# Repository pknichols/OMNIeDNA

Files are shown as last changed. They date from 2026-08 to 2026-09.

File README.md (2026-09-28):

# OMNIeDNA (*O*pen, *M*odular, *N*on-invasive, *I*n-situ eDNA) Sampler
## The versatile 3D-printed eDNA sampler to maximize detection and minimize complexity

---

> [!IMPORTANT]
> **Preliminary tool, subject to on-going development.**

<p align="center">
  OMNIeDNA
</p>

The OMNIeDNA sampler is a modular environmental DNA (eDNA) concentration system built around a standard 50 mm cotton swab pad secured within a threaded connection ring. By placing this simple, low-cost membrane at the point of water entry, the OMNIeDNA filter system creates a consistent, focused filtration interface that works across virtually any water sampling scenario. Yes, you can also use more traditional filter membranes (48-52 mm diameter) if you feel so inclined!

Whether deployed passively or with minimal active force, the system directs water through the cotton membrane, capturing cellular material and extracellular DNA efficiently on a substrate that is both widely available and easily processed for downstream DNA extraction. The threaded ring architecture allows users to adapt the same filtration core to a wide range of sampling containers, flow conditions, or collection methods, making affordable ecosystem-wide surveying accessible in diverse environments. The OMNIeDNA filter system is an inexpensive tool that puts the power of eDNA sampling into the hands of non-specialist users. Simple materials, limitless adaptability.

<p align="center">
  torrent
</p>

- [**OMNIeDNA TORRENT**](./OMNIeDNA_TORRENT_kit.stl) – A torpedo-shaped sampler designed specifically for use in streams and rivers, or to be deployed from behind recreational vessels and/or watercraft. So versatile that it can be deployed using buoys, docks, bridges, kayaks, dinghies, SUPs... heck, we'd even tie it to a unicorn floaty! Use the [**OMNIeDNA TORRENT MINI**](./OMNIeDNA_TORRENT_MINI_kit.stl) on a fishing pole for casting or trolling for eDNA!

&nbsp;

---

<p align="center">
  omnifilter_rapid
</p>

- [**OMNIeDNA RAPID**](./OMNIeDNA_RAPID_kit.stl) – Universal 1.0/1.5-liter plastic bottle threaded attachment (PET bottles with the standard 30 mm caps) for rapid filtering of collected water samples. Make sure you enjoy that soda first though, and give it a good cleaning before use!

&nbsp;

---

<p align="center">
  omnifilter
</p>

- [**OMNIeDNA BULK**](./OMNIeDNA_BULK_kit.stl) – Universal 5.0/5.1-liter plastic bottle threaded attachment (PET carboys with a 50 mm cap) for large-volume filtration of collected water samples. You know, the kind of water jugs you keep in the hidden bunker for the zombie apocalypse?

&nbsp;

---

<p align="center">
  canopy
</p>

- [**OMNIeDNA CANOPY**](./OMNIeDNA_CANOPY_kit.stl) – A rain/sleet/snow collection adapter to maximize filtration of canopy throughfall. When used in the rain with a plastic tarp (sorry, cannot 3D print that piece), the attached plastic bottle lets you know how much water you have collected. When used in sleet/snow, bring the bottle to room temperature to melt and invert to filter the collected water. We didn't want to exclude our (Ant)arctic partners!!

&nbsp;

---

<p align="center">
  omnicartridge
</p>

- [**OMNIeDNA Cartridges**](./Optional/mixed_bed2x2.stl) – Reusable filter membrane holders (for use with filter membranes of diameter < 52 mm) enable adjustable pre-filtration based on debris load and environment type, allow sterile batch assembly for fast field deployment, and are easy to decontaminate after use.

&nbsp;

---

<p align="center">
  multi_rack
</p>

- [**OMNIeDNA Multi Rack**](./Optional/multi_rack.stl) – Facilitates the transfer of filter membranes into sample storage tubes in the laboratory or field. Steadily holds 15 mL and 5 mL conical tubes, plus two OMNIeDNA Cartridges. Drainage holes for easy bleach-decontamination and drying.

&nbsp;

&nbsp;

---

## Instructions

The OMNIeDNA system may look complex with a lot of pieces, but whether you're dangling it off a boat or screwing it onto a soda bottle on shore, you only ever need **one of each** to get rolling.

We call it **The ABCs**. Pick your **A**, pick your **B**, pick your **C**, and you are ready to sample.

**That's it.** Three pieces. So many configurations. Go get that eDNA. 🧬

&nbsp;

### (A) – The Adapter

This is the top half. It's where the water enters the system. Your choice depends on where you plan to sample:

| Adapter | Other Required Gear | Best Suited For | Filament Used | Approx. Print Time | Print Settings |
|---|---|---|-----|---|---|
| [**TORRENT Cone**](./A_components/torrent_cone.stl) | TORRENT Tail, rope | Moving aquatic environments (rivers, streams, towed behind a kayak or small boat) | 40g | 1hr 15min | Brim only |
| [**RAPID Adapter**](./A_components/rapid_adapter.stl) | 1.0/1.5L plastic bottles, Wide/Narrow Base | Great for quick, grab-and-go field sampling. Uses plastic bottles that are universally available. | 50g | 2hr 5min | Brim only |
| [**BULK Adapter**](./A_components/bulk_adapter.stl) | 5.1L plastic carboy, Wide Base | Perfect for sampling water from larger jugs, meaning more eDNA. However, larger jugs may be more difficult to source. | 55g | 2hr 15min | Brim only |

&nbsp;

---

### (B) – The Base

This is the bottom half. It dictates how the sampler stabilizes while water flows out.

| Base | Other Required Gear | Best Suited For | Filament Used | Approx. Print Time | Print Settings |
|---|---|---|-----|---|---|
| [**TORRENT Tail**](./B_components/torrent_tail.stl) | TORRENT Cone, rope | Moving aquatic environments (rivers, streams, towed behind a kayak or small boat) | 240g | 10hr | Outer Brim, 50% infill |
| **Wide Base** | BULK or RAPID Adapter, 5.1L or 1.0/1.5L plastic bottle | Dry land / bench-top filtration, with a sturdy footprint that is less likely to tip over while you work | | | Outer Brim |
| [**Narrow Base**](./B_components/narrow_base.stl) | BULK or RAPID Adapter, 5.1L or 1.0/1.5L plastic bottle | Compact fieldwork (coolers, backpacks, tight spaces) or uneven ground where it can instead be hung for maximum portability | 35g | 1hr 30min | Outer Brim |
| [**CANOPY Bulkhead**](./B_components/canopy_bulkhead.stl) | BULK or RAPID Adapter, 5.1L or 1.0/1.5L plastic bottle, durable plastic sheet (waterproof tarp, shower curtain liner, etc.), rope | Used as a through-fitting for a large plastic sheet or tarp to collect rainwater while suspended from the trees | 25g | 1hr 30min | Tight supports |

&nbsp;

---

### (C) – The Connector

This is the middle piece... a threaded ring that literally **connects your chosen (A) to your chosen (B)**.

| Connector | Required For | Filament Used | Approx. Print Time | Print Settings |
|---|---|-----|---|---|
| [**Connector Ring**](./C_components/connector_ring.stl) | All builds | 20g | 40min | Outer Brim |

&nbsp;

---

### Optional Extras

For fragile filter membranes (or those < 50 mm in diameter), the OMNIeDNA Cartridges are highly recommended to provide stability and reduce likelihood of filter membrane loss.

- Pre-load your sterile filter membranes *before* you leave. No more fumbling with delicate filter membranes in the field!
- At the field site, just pop the cartridge in, sample, pop it out, and seal it in a plastic bag.
- Putting your filter membranes into sample tubes? Use the tube rack as a stable platform to transfer membranes from cartridges to 15 or 5 mL conical sample tubes.

| Extra | Description | Filament Used | Approx. Print Time | Print Settings |
|---|---|-----|---|---|
| [**Support Cartridge**](./Optional/support_cartridge.stl) | 6 mm openings to provide support for fragile filter membranes while maximizing the contact area of filtered water | 5g | 20min | 100% infill |
| [**Mesh Cartridge**](./Optional/mesh_cartridge.stl) | Fine 2.5 mm mesh for excluding large debris like leaves, sticks, and other material that may be in the water. It also provides support for fragile filter membranes, reducing the chances of them ripping during deployments | 5g | 15min | 100% infill |
| [**Multi Rack**](./Optional/multi_rack.stl) | Tube rack for holding samples while in the laboratory or in the field, greatly reducing the chances of knocking something over. Even holds two membrane cartridges for easy transfer directly into sample storage tubes. | 110g | 3hr 45min | Outer Brim |

&nbsp;

&nbsp;

---

### Putting It All Together

Here are some theoretical builds/use cases (no, we haven't tested them all... yet):

| Use Case | System | Printed Parts | Justification |
|---|----|---|---|
| *What fish are in my local river? (Mostly curious)* | TORRENT | [**TORRENT Cone (A)**](./A_components/torrent_cone.stl), [**TORRENT Tail (B)**](./B_components/torrent_tail.stl), [**Connector Ring (C)**](./C_components/connector_ring.stl), [**Mesh Cartridge (Optional)**](./Optional/mesh_cartridge.stl) | Moving water requires the torpedo-shaped [**OMNIeDNA TORRENT**](./OMNIeDNA_TORRENT_kit.stl) to guide water through the opening. Use a mesh cartridge to keep out larger debris and focus eDNA more efficiently, while minimizing tearing of the filter membrane. |
| *What fish are in my local river? (I'm a fisherman)* | TORRENT MINI |  | Attach the torpedo-shaped [**OMNIeDNA TORRENT MINI**](./OMNIeDNA_TORRENT_MINI_kit.stl) to a fishing pole and cast out multiple times, focusing eDNA efficiently onto smaller 25 mm membranes. Simple and fun! |
| *What birds visit my birdbath?* | RAPID |[**RAPID Adapter (A)**](./A_components/rapid_adapter.stl), [**Narrow Base (B)**](./B_components/narrow_base.stl), [**Connector Ring (C)**](./C_components/connector_ring.stl) | Use a standard plastic bottle to collect birdbath water (multiple times, the more the better, but leave some for the birds!) with the [**OMNIeDNA RAPID**](./OMNIeDNA_RAPID_kit.stl). |
| *Are there aquatic invasive species here?* | BULK | [**BULK Adapter (A)**](./A_components/bulk_adapter.stl), **Wide Base (B)**, [**Connector Ring (C)**](./C_components/connector_ring.stl), [**Support Cartridge (Optional)**](./Optional/support_cartridge.stl) | Maximize detection of rare species and the volume of water that passes through the filter membrane by using a larger 5L bottle (multiple times, the more the better!) and the [**OMNIeDNA BULK**](./OMNIeDNA_BULK_kit.stl). Use the support cartridge to maximize surface area while minimizing the chances of ripping the filter membrane. |
| *What are the birds, the bees, and the trees?* | CANOPY | [**RAPID Adapter (A)**](./A_components/rapid_adapter.stl), [**CANOPY Bulkhead (B)**](./B_components/canopy_bulkhead.stl), [**Mesh Cartridge (Optional)**](./Optional/mesh_cartridge.stl) | Harvest rain throughfall under forested canopies using the [**OMNIeDNA CANOPY**](./OMNIeDNA_CANOPY_kit.stl) to easily sample plant and animal communities. Use the mesh cartridge to exclude leaves, sticks, and other debris that may be caught as well. Know how much rain you filtered by collecting it in a standard plastic bottle. |

&nbsp;

&nbsp;

---

## Helpful Tips

- **OMNIeDNA TORRENT:** The sampler stays underwater via hydrodynamic design, but it relies on water flow to maintain negative buoyancy. Securely attach a ballast weight (dive weight, brick, anchor, or large rock) to any of the gear attachment points. When you MUST add a ballast weight:

  - *Too slow:* Water speed < 1 knot (~0.5 m/s) — not enough flow to push it down.

  - *Too fast:* Water speed > 7 knots (~3.5 m/s) — risk of planing or lifting out of the water.

  - *Too deep:* Sampling near the bottom of the water column. 

- **OMNIeDNA BULK/RAPID:** When using a plastic bottle, filtration will be much easier if you can poke a hole in the bottom! That way, when you invert the system, it will drain smoothly through the filter. Use tape to temporarily seal the hole while sampling (or simpler still, just be really quick)!

- **OMNIeDNA CANOPY:** While the system can theoretically use any waterproof sheet material, those that can hold up to stormy weather, rough terrain, and routine decontamination with bleach will inevitably perform best (e.g., thick PVC). 

  - *Hanging:* Pick a location that has plenty of trees and bring plenty of extra string to secure the corners as high as you can reach.
  - *Tensioning:* Use a tensioning knot such as a prusik, taut-line hitch, or siberian hitch attached to each corner to easily adjust where water collects. Bring a bottle of water to test where it gathers.
  - *Collecting:* Poke a hole in the top of your collection bottle to allow air to easily vent and water to enter. This also allows extra water can escape during large storms, instead of pooling up on the tarp. Size your collection bottle to the expected amount of rain (i.e., RAPID adapter for quick sampling, BULK adapter for lots of rain/large surface area tarps)

&nbsp;

## Printer Specifications

All components have been successfully printed on a Prusa MK4S using the following parameters:

- **Filament:** 1.75mm PETG or ABS plastic (recommended over PLA for toughness, frequent use in harsh environments). ABS components can be smoothed with an Acetone vapor bath to facilitate routine bleach decontamination.
- **Infill:** Gyroid, 30%+ (superior strength-to-weight ratio using less material, reducing print costs)
- **Layer height:** 0.20 mm
- **Minimum perimeters per layer:** 4
- **Print temperature:** 220°C – 260°C (PETG/ABS); 
- **Heated bed:** 70 – 80°C (PETG); 90 – 110°C (ABS; enclosure and ventilation recommended)
- **Brim/supports:** 8-10mm brim when using ABS; supports were only needed for printing the Canopy_bulkhead

While these settings are optimized for PETG/ABS, users should conduct test prints to validate dimensional accuracy and layer adhesion with their chosen filament.

Printing with Prusa? We're also on [Printables.com](https://www.printables.com/search/all-models?q=OMNIeDNA)! Search 'OMNIeDNA' for easily slicing our sampler kits and components.

&nbsp;

&nbsp;

&nbsp;

## Acknowledgements

**Original concept by Patrick Nichols**  
Postdoctoral Researcher | Biodiversity Genomics Research Group | University of Oulu  

📧 [patrick.nichols@oulu.fi](mailto:patrick.nichols@oulu.fi)  
🔗 [pknichols.com](https://pknichols.com/)
🔗 [biodiversitygenomics.org](https://biodiversitygenomics.org/)

**Design by Jan Schulz**  
Social Designer

📧 [schulz.janc@gmail.com](mailto:schulz.janc@gmail.com)  
🔗 [janchristianschulz.com](https://janchristianschulz.com/)

**Design by Brendan Nichols**  
Principal Scientist, General Dynamics, Applied Physical Sciences Corp.

📧 [bnichols@aphysci.com](mailto:bnichols@aphysci.com)  

&nbsp;

&nbsp;

SAFIRE UniOulu_UNIapproved PNG+Logo+(RGB)_THULE_cmyk fabcity_oulu_logo

---

*If you use this system in your research, please cite or acknowledge the original design.*

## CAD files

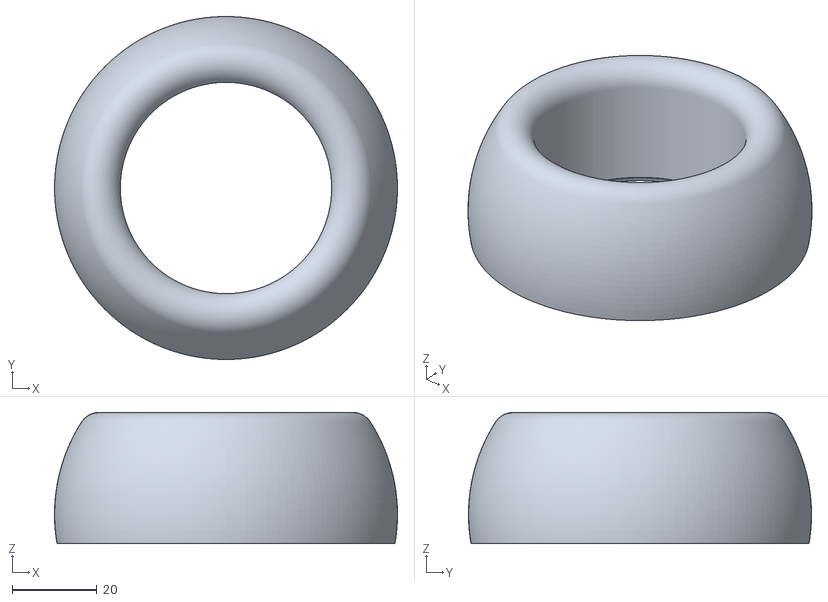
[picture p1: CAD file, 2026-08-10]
A_components/torrent_cone.stl
81.2 x 81.2 x 31.1

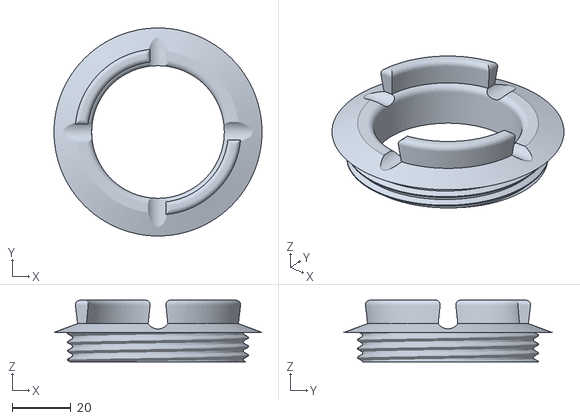
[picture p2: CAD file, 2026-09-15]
B_components/canopy_bulkhead.stl
70.6 x 70.6 x 21.0

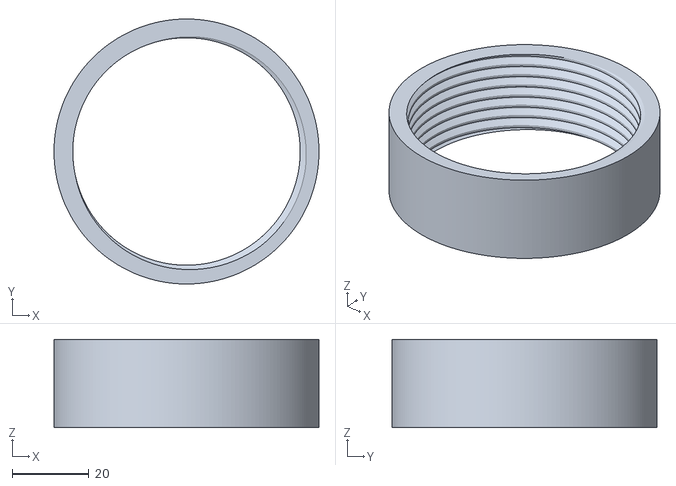
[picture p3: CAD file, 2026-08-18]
C_components/connector_ring.stl
69.0 x 69.0 x 23.0

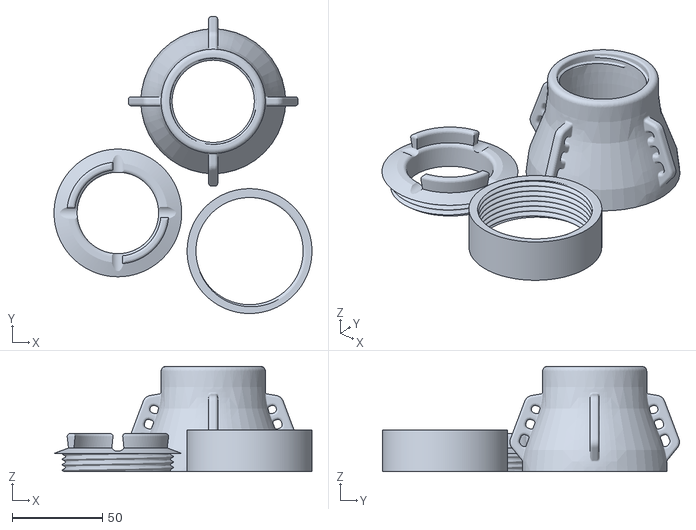
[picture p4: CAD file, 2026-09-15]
OMNIeDNA_CANOPY_kit.stl
142.6 x 164.2 x 58.1

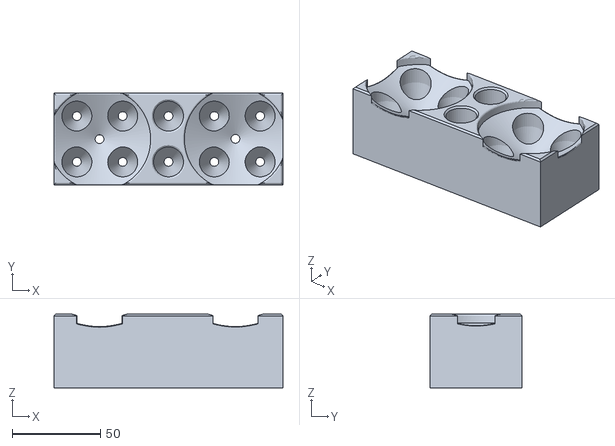
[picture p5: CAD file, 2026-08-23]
Optional/multi_rack.stl
130.0 x 52.0 x 42.0

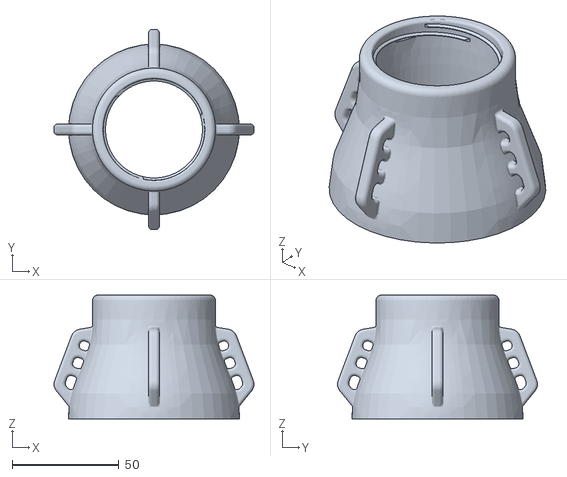
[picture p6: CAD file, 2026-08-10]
A_components/bulk_adapter.stl
93.7 x 93.7 x 58.1

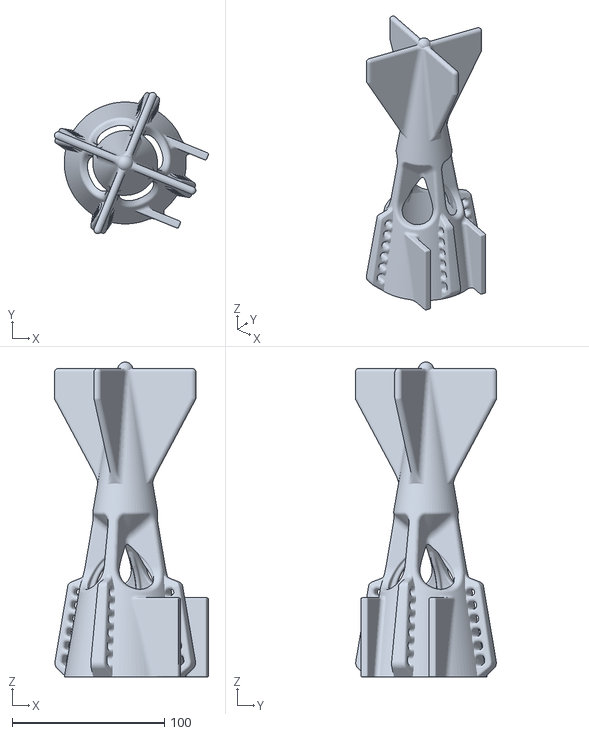
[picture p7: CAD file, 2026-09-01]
B_components/torrent_tail.stl
101.1 x 92.9 x 206.7

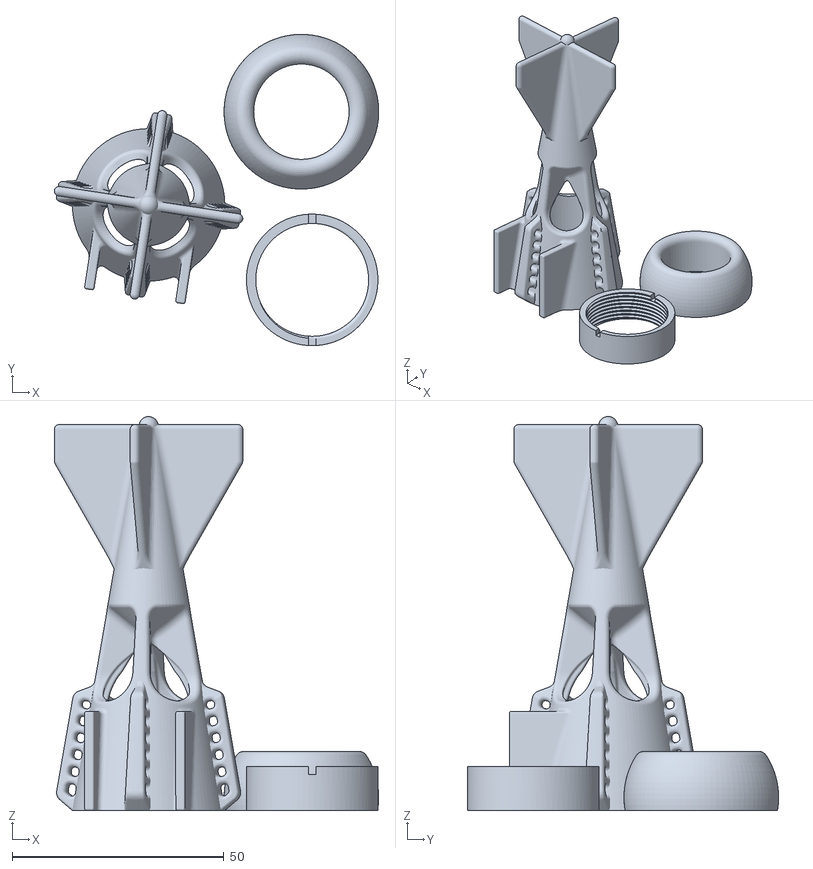
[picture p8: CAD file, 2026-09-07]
OMNIeDNA_TORRENT_MINI_kit.stl
76.6 x 73.5 x 93.0

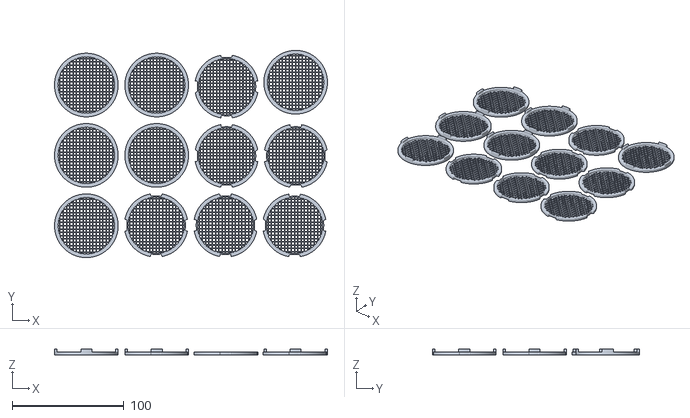
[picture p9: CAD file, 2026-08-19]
Optional/mesh_bed6x.stl
244.4 x 185.5 x 5.00

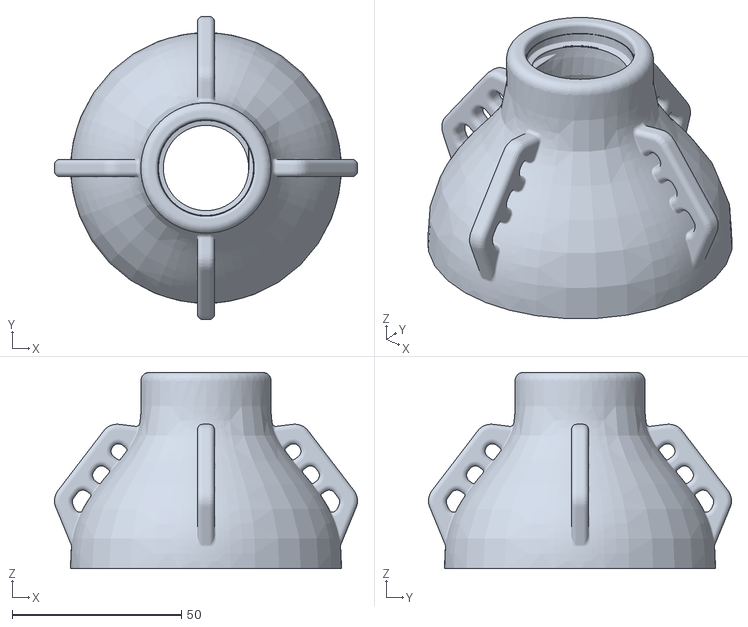
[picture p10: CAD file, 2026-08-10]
A_components/rapid_adapter.stl
89.6 x 89.6 x 58.1

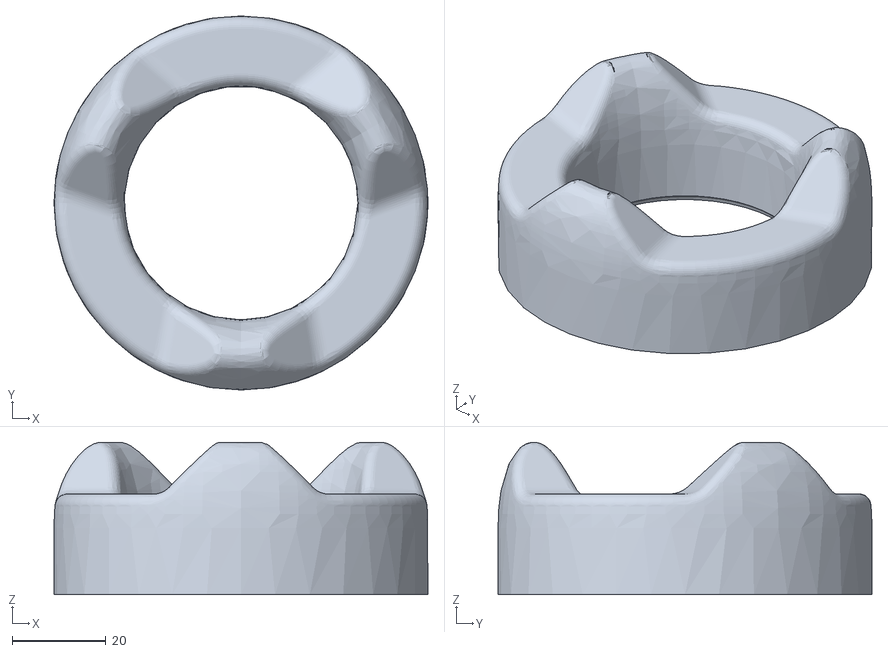
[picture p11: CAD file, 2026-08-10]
B_components/narrow_base.stl
80.0 x 80.0 x 32.6

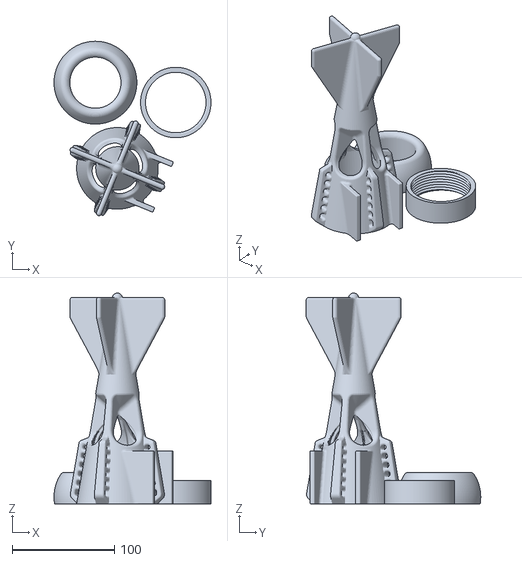
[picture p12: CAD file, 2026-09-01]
OMNIeDNA_TORRENT_kit.stl
153.8 x 171.0 x 206.7

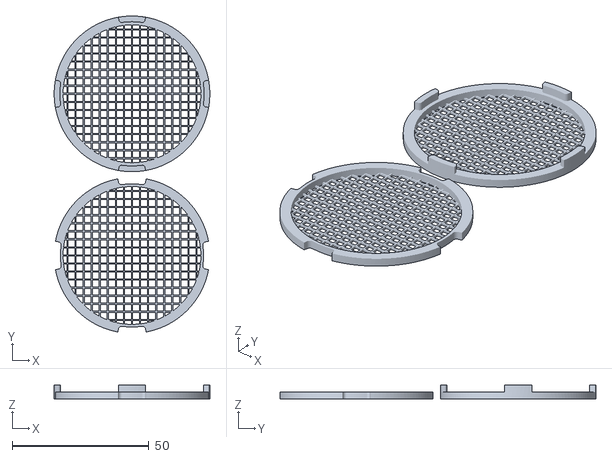
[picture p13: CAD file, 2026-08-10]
Optional/mesh_cartridge.stl
57.0 x 115.7 x 5.00

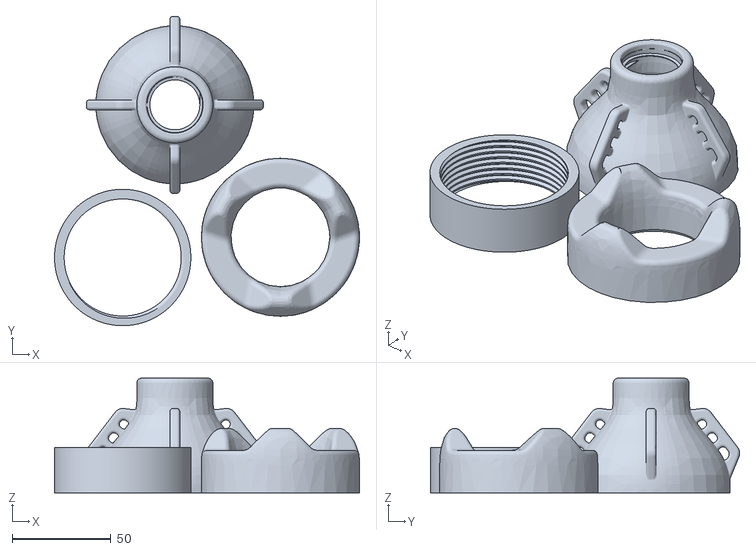
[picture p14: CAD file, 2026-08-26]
OMNIeDNA_RAPID_kit.stl
154.3 x 156.5 x 58.1

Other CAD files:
Optional/mixed_bed2x2.stl
OMNIeDNA_BULK_kit.stl
Optional/support_cartridge.stl
Optional/support_bed4x.stl
Optional/mesh_bed4x.stl
